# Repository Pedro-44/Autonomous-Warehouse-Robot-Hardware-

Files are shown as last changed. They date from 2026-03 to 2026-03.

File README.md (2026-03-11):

# Autonomous Warehouse Restocking Robot (TRL 3 Prototype)

An autonomous mobile robot designed to identify, collect, and restock grocery items on various shelving units within a simulated grocery store environment. This project was developed as part of the **EGB320 - Mechatronics Design II** course at the **Queensland University of Technology (QUT)**.

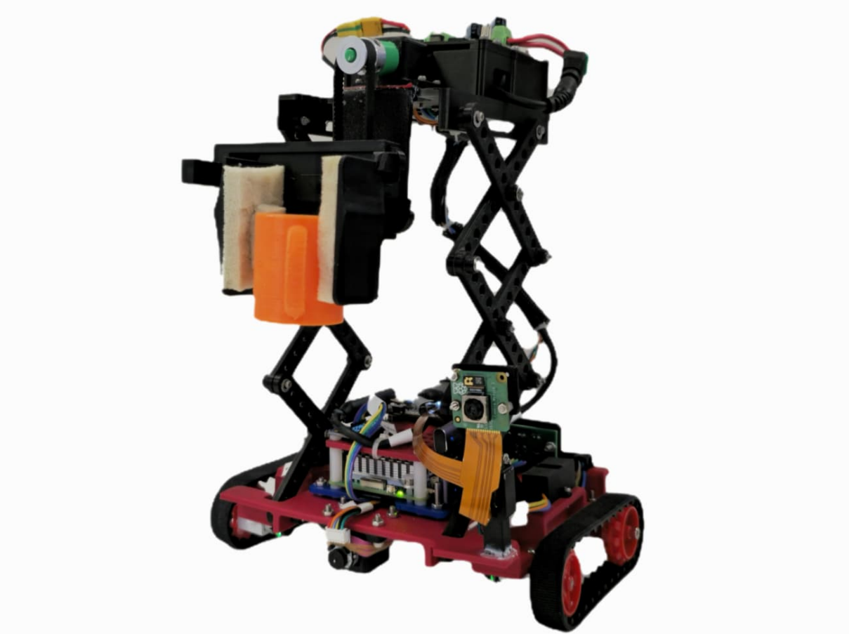
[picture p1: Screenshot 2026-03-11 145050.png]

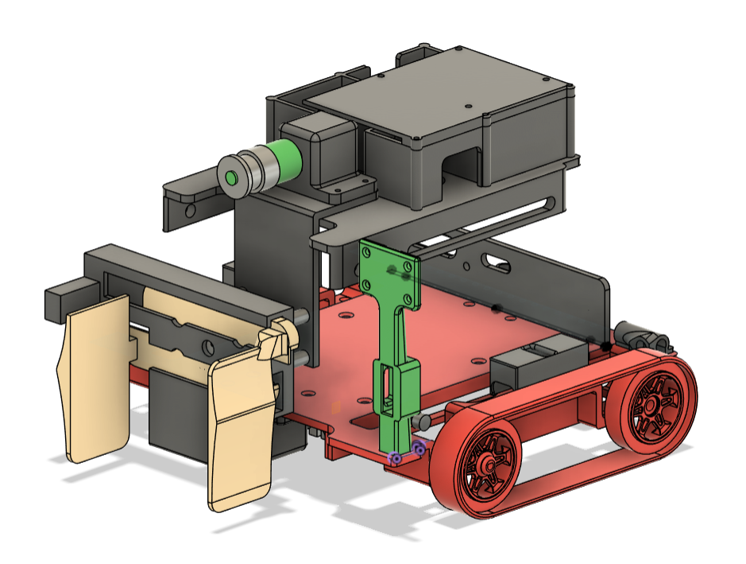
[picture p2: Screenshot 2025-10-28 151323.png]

---

## 🛠️ Subsystem Spotlight: Item Collection
I was responsible for the research, design, and testing of the **Item Collection Subsystem**, which is divided into lifting and grabbing mechanics.

### 1. Mechanical Design
* **Vertical Scissor Lift:** Selected for its vertical motion, which simplifies software calculations by keeping the robot at a constant distance from shelves regardless of height.
* **Lead Screw Actuation:** Converts the rotational motion of a DC motor into linear displacement. The added friction acts as a lock, preventing the lift from falling without continuous power.
* **Parallel Rack-and-Pinion Gripper:** Chosen for its mechanical simplicity and ability to ensure even gripping forces on objects of varying shapes.
* **3D Printed Components:** All lifting and gripping components were modeled in Autodesk Fusion 360 and produced via 3D printing through multiple iterations.

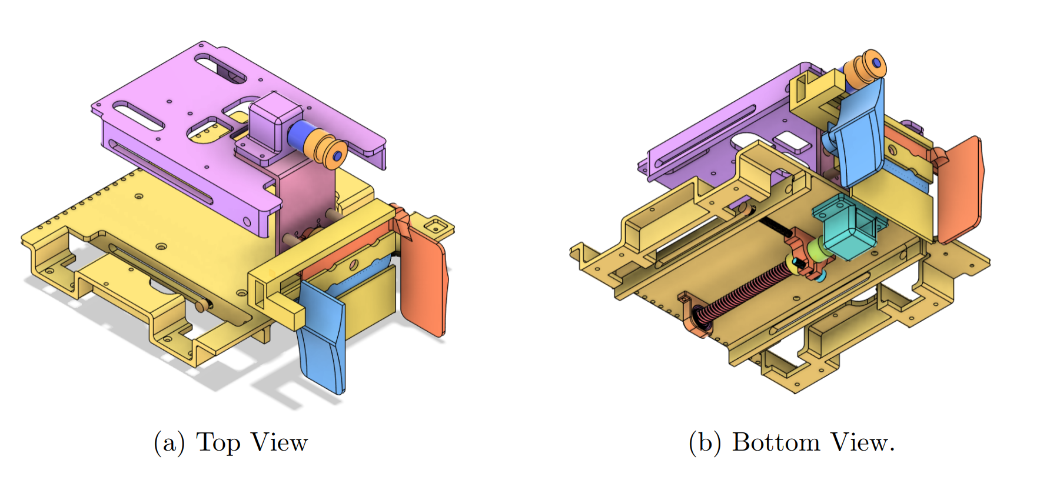
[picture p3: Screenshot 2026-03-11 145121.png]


### 2. Electronics & Control
* **Actuators:** Utilized **N20 Encoded Gear Motors** for both mechanisms to provide required torque and precise position feedback.
* **Power System:** Powered by a 7.4V nominal voltage battery. A buck converter regulates 5.1V for the **Raspberry Pi 5**, while an unregulated line supplies the motor driver (H-Bridge).
* **Communication:** Commands are sent via a serial interface from the Raspberry Pi to the motor controller to regulate motor speed, direction, and position.

### 3. Software Architecture
The system utilizes Python-based functions to communicate with the motor controller via Serial:
* `lift_level(level)`: Uses positional control to raise the lift to ground level or three specific shelf heights.
* `grip(job)`: Controls the gripper to open, close, or stop.
* **Contact Detection:** For closing, the controller monitors encoder values and grabs the object when the velocity reaches a certain threshold.

---

## 📊 Performance & Validation
The subsystem was verified against functional requirements through experimental testing.

| Parameter | Specification | Result | Status |
| :--- | :--- | :--- | :--- |
| **Vertical Range** | 250 mm | 254 mm | **PASS** |
| **Payload Capacity** | 0.5 kg | 0.15 kg | **FAIL** |
| **Angular Tilt** | < 7° | 5° at Max Height | **PASS** |
| **Lifting Speed** | 3.0 s | 6.13 s (at 0g payload) | **FAIL** |

**Key Finding:** Integration testing confirmed the robot maintains stability navigating ramps at Level 1, but loses its center of balance if the collection subsystem is raised higher than Level 1 during movement.

---

## 🚀 Future Improvements
* **Durability:** Replacing 3D-printed joints with metal or ball-bearing pivots to improve precision and reduce friction.
* **Structural Rigidity:** Using laser-cut acrylic for linkages to provide more rigidity than standard plastic.
* **Speed Optimization:** Increasing lifting speed by optimizing the lead screw pitch or using a higher-speed motor.

---

### 📂 Repository Structure
* `/CAD`: Fusion 360 models and linkage drawings.
* `/Code`: Python scripts for serial communication and level control.
* `/Documentation`: Full technical report including power flow and logic diagrams.

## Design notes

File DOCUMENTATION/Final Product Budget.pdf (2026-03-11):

Item Name | Part No. | Supplier URL | Price (AUD) | Qty | Total (AUD)
Raspberry Pi Camera | - | | 40 | 1 | 40
LED PCB | - | | 0.64 | 1 | 0.64
3501 Series Lead Screw (8mm Lead, 4 Start, 100mm Length) | GB-3501-0804-0100 | https://core-electronics.com.au/3501-series-lead-screw-8mm-lead-4-start-100mm-length.html | 8.45 | 1 | 8.45
611 Series Flanged Ball Bearing (8mm ID x 14mm OD, 5mm Thickness) - 2 Pack | GB-1611-0514-0008 | https://core-electronics.com.au/1611-series-flanged-ball-bearing-8mm-id-x-14mm-od-5mm-thickness-2-pack.html | 7.2 | 1 | 7.2

N20 DC Gear Motor
with Magnetic Hall
Encoder | WS-26377

https://core-electronics.com.au/n20-dcgear-motor-magnetic-hall-encoder-allmetal-gearbox-high-precision-reduction-
motor-with-l-shaped-6pin- | 14.75 | 4 | 59
Pololu 30T Track Set - Red | SKU-004199 | https://www.robotgear.com.au/Product.aspx/Details/5353-Pololu-30T-Track-Set-Red 25.95 | | 1 | 25.95
DC-DC Power Module 25W | DFR0205 | https://core-electronics.com.au/dc-dc-power-module-25w.html | 15.35 | 1 | 15.35
Blue LED | 732-5016-ND | https://www.digikey.com.au/en/products/detail/w-rth-elektronik/151051BS04000/4490009?g | 0.38 | 1 | 0.38
Red LED | 732-5016-ND | https://www.digikey.com.au/en/products/detail/w-rth-elektronik/151051RS11000/4490012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 sfHBhB6EiwAQtv5qRqiv6Qx8LxBxTXWv _67WwsDdcAEoPuX5r5u- | 0.24 | 1 | 0.24
Yellow LED | 732-5018-ND | https://www.digikey.com.au/en/products/detail/w-rth-elektronik/151051YS04000/4490018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 AQtv5qbH60ZwvTAfcKd8nbiuJ5KKtpNJ Q6_wUuw_0vFjLwXJ0rvItGtOHzhoCGA | 0.31 | 1 | 0.31
USB-A to USB-C Cable | CE09403 | https://core-electronics.com.au/usb-a-to-c-cable-1m- | 1.75 | 1 | 1.75

Final Product Budget

150 ohm Resistor | 2019-CF1/2C151J-ND | https://www.digikey.com.au/en/products/detail/koa-speer-electronics-inc/CF1-2C151J/21681808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 iwAQtv5qaiMsCVhcBYGK-0RCW7fpBYDG4SsB4S1j8aCzOc3Z-iS1fApda_4qxoC0hMQAvD_BwE | 0.2 | 4 | 0.8
USB-C MALE-FEMALE L ADAPTER | PSG91737 | https://au.element14.com/pro-signal/psg91737/usb-c-male-female-l-shaped-adapter/dp/469058001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|pcrid|380892800521|p kw||pmt||slid||product|469058001|p grid|76493923343|ptaid|aud-471864486199:pla-293946777986|&gad_source=1&gad_c ampaignid=179235048&gbraid=0AAAA AD8yeHk6KGNaao3dUqmd1QZaoV6ZP &gclid=CjwKCAjw0sfHBhB6EiwAQtv5qT | 2.89 | 3 | 8.67
USB Type C 3.1 PD to 5.5mm Barrel Jack Cable - 12V 5A Output | PP2070 | https://www.jaycar.com.au/usb-type-c-3-1-pd-to-5-5mm-barrel-jack-cable-12v-5a-output-1-2m-long/p/PP2070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 | 9.95 | 1 | 9.95
Female DC Barrel Jack Adapter (2.1mm) | CE08698 | https://core-electronics.com.au/female-dc-barrel-jack-adapter-21mm.html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 | 1.4 | 1 | 1.4
Machine Screw: M2.5, Phillips (25-pack) | SKU-002931 | https://www.robotgear.com.au/Product.aspx/Details/4033-Machine-Screw-M2-5-6mm-Length-Phillips-25-pack | 3.5 | 1 | 3.5
Machine Hex Nut: | SKU-002930 | https://www.robotgear.com.au/Produc | 4.95 | 1 | 4.95
Jumper Jerky Junior Wires | PI-CAB0003 | https://littlebirdelectronics.com.au/collections/jumpers-wires/products/jumper-jerky-junior- | 2.13 | 1 | 2.13
Final Weight | - | - | 10 | 0.8 | 8
TOTAL | | | | | 198.67

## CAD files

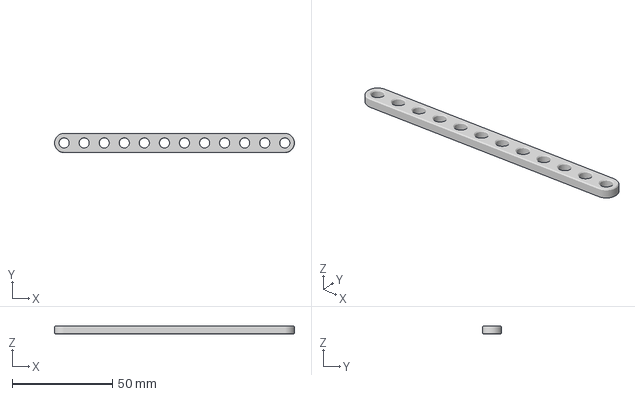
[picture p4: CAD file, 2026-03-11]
CAD/Link - 12 Full Body.3mf
119.6 x 9.60 x 4.00 mm

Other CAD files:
CAD/EGB320 Final CAD.f3z

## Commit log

2026-03-11 CAD fils
    [Back Up Mechanism (Milestone3 but higher base)) v9.3mf, Link - 12 Full Body.3mf]
2026-03-11 Create link - 12 Full Body.3mf
    [link - 12 Full Body.3mf]
2026-03-11 Added CAD files
    [EGB320 Final CAD.f3z, Link - 12 Full Body.3mf]
